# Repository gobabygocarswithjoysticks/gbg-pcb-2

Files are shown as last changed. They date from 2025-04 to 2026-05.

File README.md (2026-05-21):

# Moved to https://github.com/gobabygocarswithjoysticks/gbg-pcb

# GBG PCB

# A PCB for controlling the motors in a [go baby go car with joystick control](https://gobabygocarswithjoysticks.github.io/index/)

https://github.com/gobabygocarswithjoysticks/gbg-pcb



V2.1

This board replaces the control box of a car's original electronics or the separate ESCs and Arduino in the [usual joystick modification](https://gobabygocarswithjoysticks.github.io/index/). The board has screw terminals for connecting to the battery, motors, and the joystick. With this circuit board, a car can be converted to joystick control without any soldering.

Voltage input: 5 to 26 volts (6v, 12v, and 24v lead acid batteries, absolute maximum 4.6V-28V)

Controls two motors: one for each wheel so that the car can turn in place.

[New in version 2](https://gobabygocarswithjoysticks.github.io/gbg-pcb/instructions/instructions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): A V2 GBG-PCB can be configured with battery, motor, and signal plugs that match the plugs on the common weelye control boxes. This means some cars can be converted to joystick control without cutting any wires. V2 GBG-PCBs also run fron 6 to 24 volt batteries.

### For the previous versions of the GBG-PCB see https://github.com/gobabygocarswithjoysticks/gbg-pcb/tree/version_1 
Version 1 GBG-PCBs had a higher, 10 amp current capacity and a lower part count but requires 12 volts.

## Questions? Please email our support line at gbg-pcb@googlegroups.com

# Want one?
* Email pnwassistivetech@gmail.com or visit the [PNW Assistive Technology website](TODO/gbg-pcb). Thank you to PNWAT for supporting this project and being a supplier of these boards.
* Use this PCBWay link to order fully assembled boards: [PCBWay](https://www.pcbway.com/project/shareproject/GBG_PCB_Go_Baby_Go_Printed_Circuit_Board_V2_0_a8fd7fa3.html)
* Email gobabygocarswithjoysticks@gmail.com. I may have a small number of assembled V1 and V2 boards to sell or donate to you.
* Or please feel free to use these [files](/PCB_production) and get boards yourself. Instructions [here](https://gobabygocarswithjoysticks.github.io/gbg-pcb/instructions/how-to-make-boards)

# Software
## The website for uploading software to a GBG-PCB and adjusting settings is here: https://gobabygocarswithjoysticks.github.io/programmer/

# Instructions
## [general instructions for using this PCB](https://gobabygocarswithjoysticks.github.io/gbg-pcb/instructions/instructions)
### [instructions for assembling your own GBG-PCBs](https://gobabygocarswithjoysticks.github.io/gbg-pcb/instructions/how-to-make-boards)
## Index of Instructions for modifying specific models of cars using GBG-PCBs
* [Aosom Jeep - old model](https://gobabygocarswithjoysticks.github.io/gbg-pcb/instructions/car-specific/aosom-038-jeep/instructions) (car is out of production)
* [Zupapa Bumper Car](https://gobabygocarswithjoysticks.github.io/gbg-pcb/instructions/car-specific/zupapa-bumper-car/instructions) (instructions are complete through electronics but don't include a backrest or joystick holder)

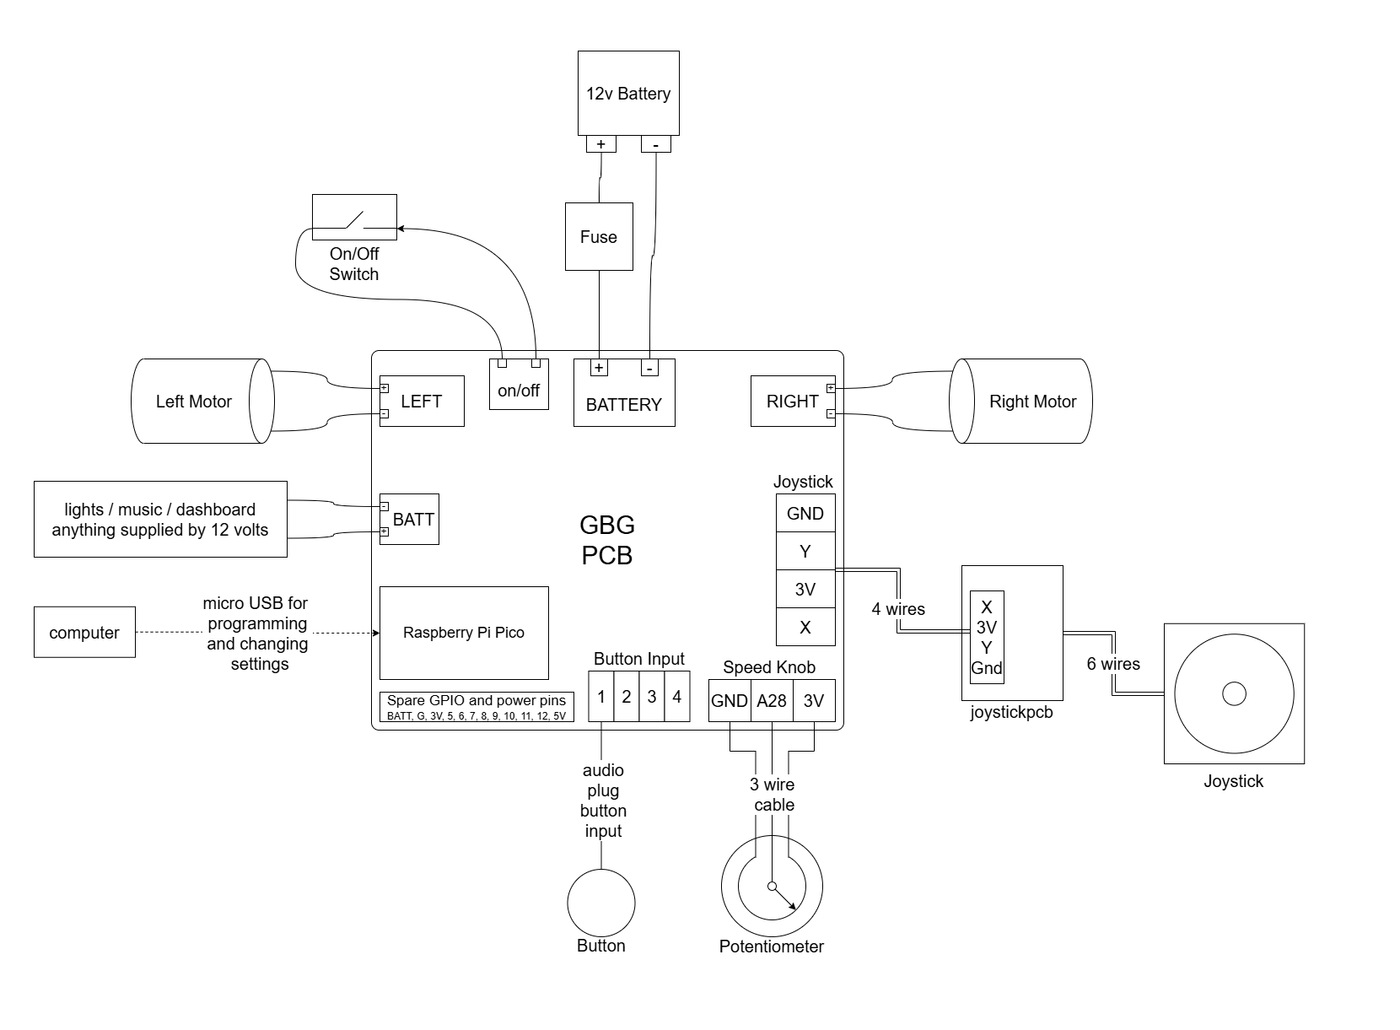
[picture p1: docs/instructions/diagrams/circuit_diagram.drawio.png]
schematic


# [schematic of PCB](/schematic.pdf)

# [PCB Production files](/PCB_production)

# [joystick to 4 wire cable connector PCB](https://github.com/gobabygocarswithjoysticks/gbg-pcb/tree/main/joystickpcb)
### This keeps you from needing to solder the joystick wires to a 4 wire cable.

# notes for people working on the KiCAD for this project
Use KiCAD 10.0

Run [this github action](https://github.com/gobabygocarswithjoysticks/gbg-pcb/actions/workflows/process-kicad.yml) when you push changes to any of the KiCAD files. The action updates the images of the CAD, the gerber files, the schematic, and other PCB production files. 

# photos
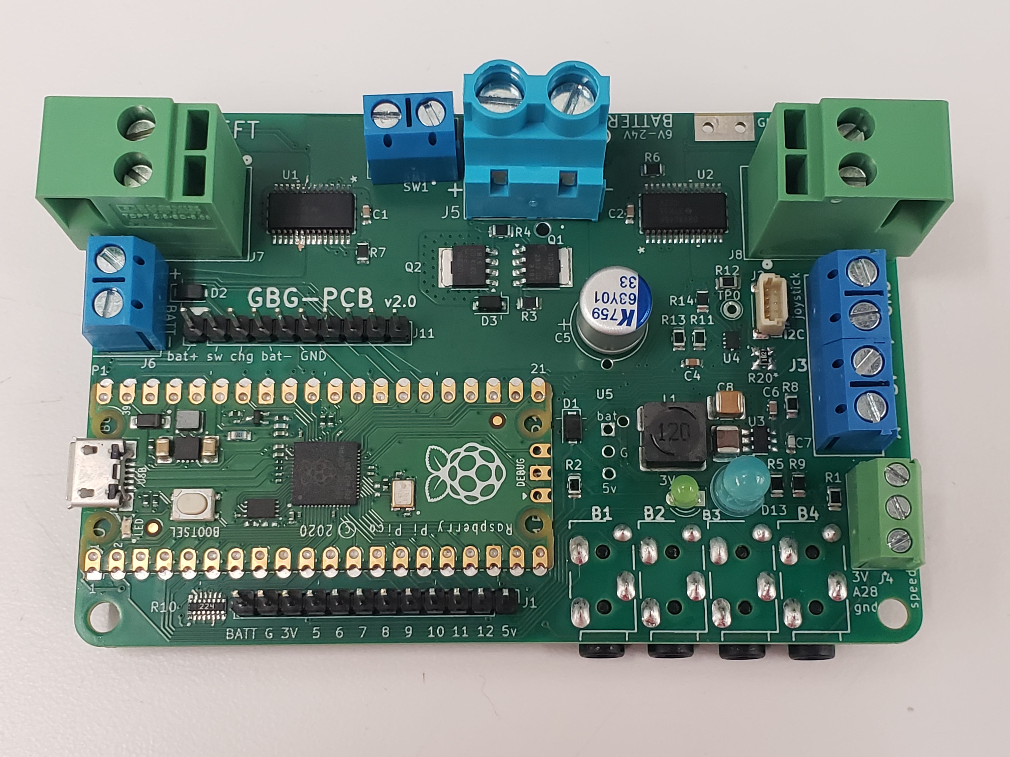
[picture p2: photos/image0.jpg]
view of assembled PCB from the top

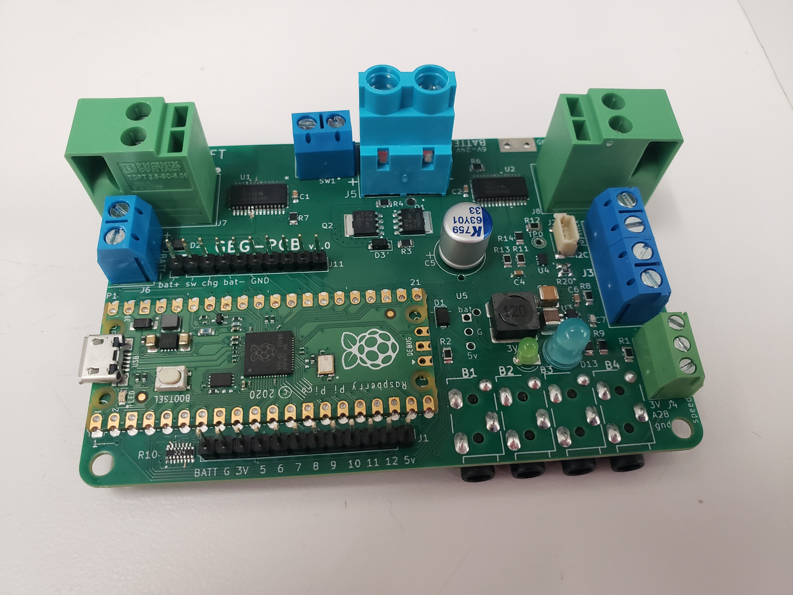
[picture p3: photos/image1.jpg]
view of assembled PCB


# images of CAD

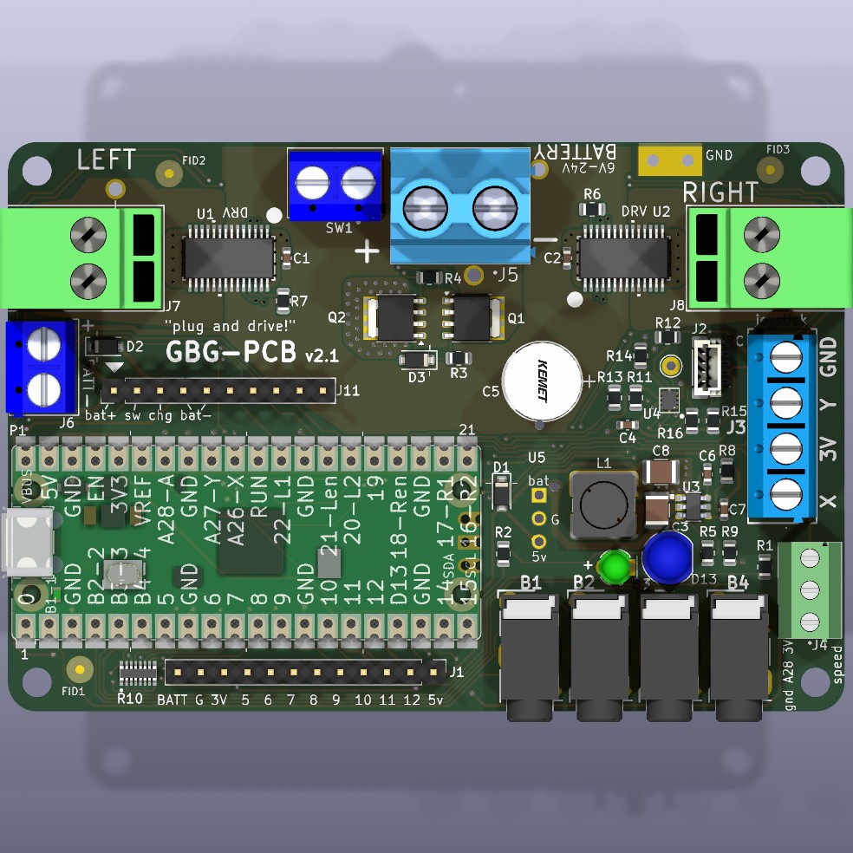
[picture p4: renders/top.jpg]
auto generated image, top view

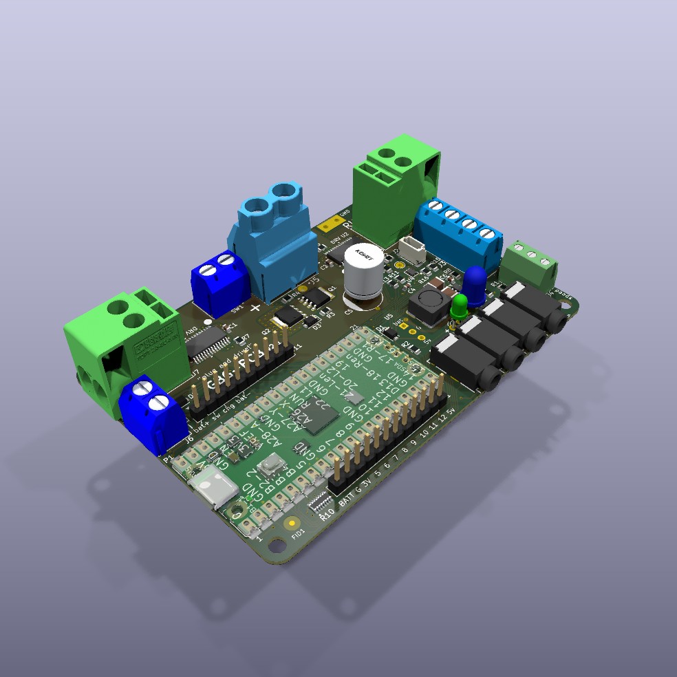
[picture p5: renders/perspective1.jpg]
auto generated image, p1

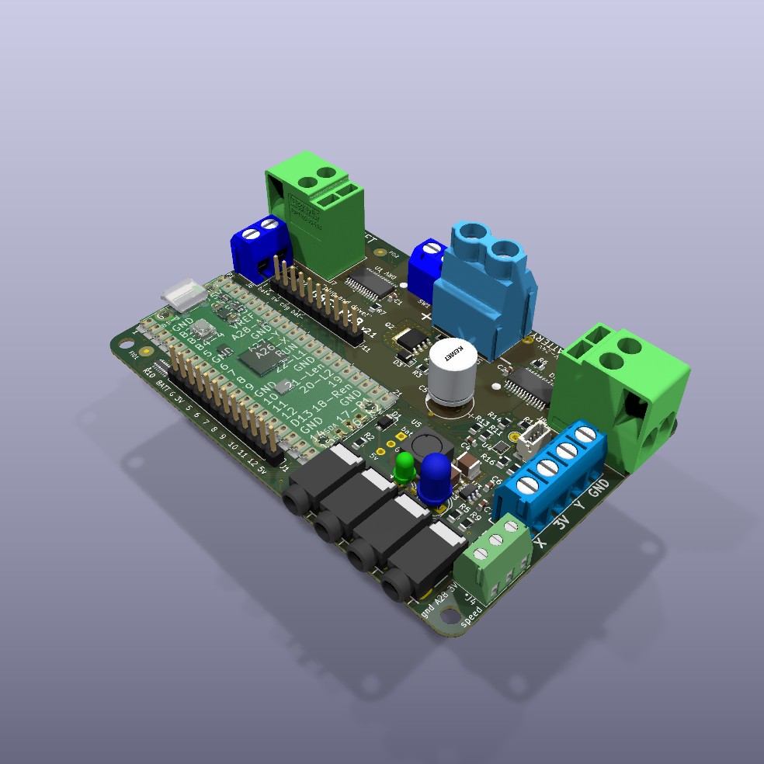
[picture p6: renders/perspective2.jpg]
auto generated image, p2

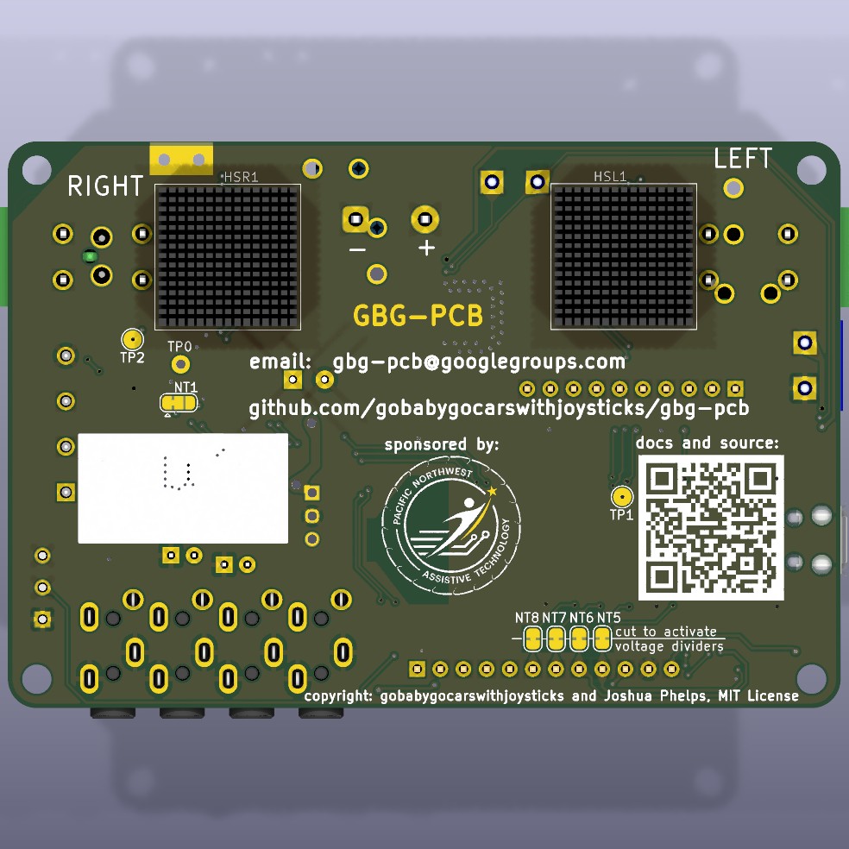
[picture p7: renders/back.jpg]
auto_generated_image, back


# credits

## Prototype boards sponsored by PNW Assistive Technology

## This project was inspired by the [Go Baby Go project](https://health.oregonstate.edu/gobabygo) that modifies powerwheels cars for kids with disabilities

## Copyright: gobabygocarswithjoysticks and Joshua Phelps, MIT License

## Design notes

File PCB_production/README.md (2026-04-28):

## instructions for how to make GBG-PCBs by hand are [here](https://gobabygocarswithjoysticks.github.io/gbg-pcb/instructions/how-to-make-boards)

## send [gerbers.zip](/PCB_production/gerbers.zip) to a PCB fabrication company

## [F_SolderPasteMask.dxf](/PCB_production/F_SolderPasteMask.dxf) can be used to get a solder stencil

## The [position.csv](/PCB_production/position.csv) file has the locations for the surface mount components

## Bill Of Materials (BOM)
please email gobabygocarswithjoysticks@gmail.com if components are out of stock and you need recommendations for alternatives

[BOM.csv](/PCB_production/BOM.csv) is the normal list of parts (using screw terminals for connections).

[BOM-with-DNP.csv](/PCB_production/BOM-with-DNP.csv) includes alternative parts that you could choose some of, for other configurations of the board.

Here is BOM.csv uploaded to a [Digikey list](https://www.digikey.com/en/mylists/list/1ZSY7GGAFQ)

## [joystick to 4 wire cable connector PCB](https://github.com/gobabygocarswithjoysticks/gbg-pcb/tree/main/joystickpcb)
This keeps you from needing to solder the joystick wires to a 4 wire cable.

## [interactive BOM to help with assembly](https://gobabygocarswithjoysticks.github.io/gbg-pcb-2/ibom/ibom.html)

## parameters for PCBs:
* 1oz copper
* 1.0mm board thickness
* 5mil/5mil
* 0.25mm holes
* solder stencils should be 0.12mm
* solder stencils should be "non-framework"
* I suggest lead-free HASL, but match your solder type

## other configurations

### alternate voltage regulator (U5)
Replace U3, C3, R5, C6, L1, C7, R8, R9, C8

Choose a single THT module that outputs 5V. Make sure the pinout matches. Make sure hte min and max input voltage are compatible with your battery. It's ok if the output voltage sags below 5 volts as the input approaches 5 volts but make sure the regulator you choose doesn't start blinking on and off as the input approaches 5 volts, if you plan to use cars with 6 volt batteries.

Consider pololu5593, D78B05T, RBT05W24S05

### alternate battery and motor connectors (Weelye mode)
The GBG-PCB includes pads for adding connectors that match the connectors on some common weelye control boxes like the RX22 and RX7.

* J102 and J103 replace J5
* J100 and J101 replace J7
* J104 replaces J8

### other models of Raspberry Pi Pico (P1)
If you want to be able to change settings and remote override the car over a wifi connection [(see information here)](https://github.com/gobabygocarswithjoysticks/car-code/blob/main/rcdocs/remote_control.md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) then you can substitute a Pico 1W or Pico 2W for the standard Pico 1.

### cost saving by removing optional features

#### button ports
If you know that you will only use joystick input and won't use button input you can omit 

B1, B2, B3, B4

#### i2c connector
If you don't plan to connect I2C devices (most likely you don't need this) you can omit

J2

#### battery and current monitor
If you don't need the PCB to be able to detect low battery voltage or how much current the motors are drawing you can omit the following parts:

U4, R11, R12, R13, R14, R20, C4

#### speed knob
If you know that you will not install a speed adjustment knob you can omit 

J4

#### [consider an alternate voltage regulator](https://github.com/gobabygocarswithjoysticks/gbg-pcb-2/blob/main/PCB_production/README.md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)

Using a THT module might not be significantly cheaper but it could save you time during assembly.

## questions for suppliers to ask
* pico1 or pico1W?
* include button jacks?
* include chip that monitors voltage and current?
* screw terminals or "weelye mode"?
    * if weelye mode, the standard headers for J11 could be changed to match the specific boards you're using

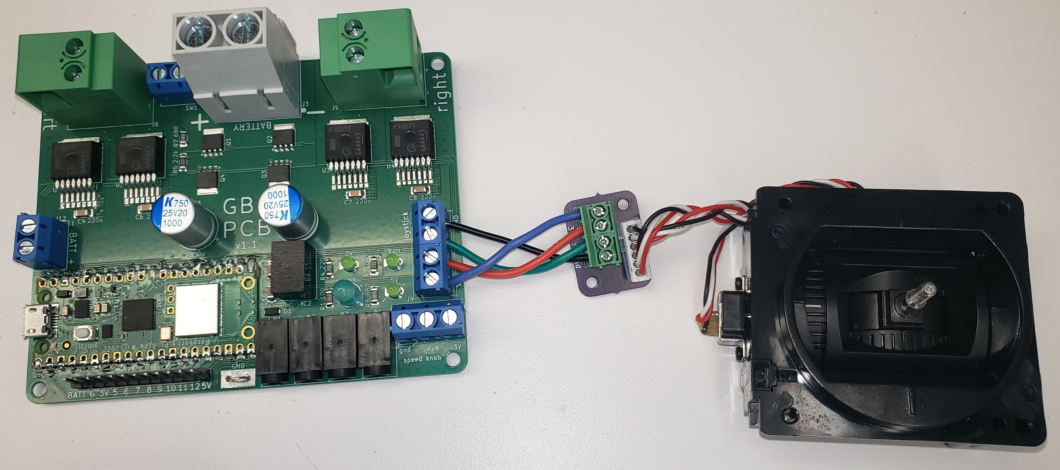
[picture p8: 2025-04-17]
photos/joystick.jpg

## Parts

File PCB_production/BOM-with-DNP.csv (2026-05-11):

Reference | Value | Footprint | Manufacturer_Name | Manufacturer_Part_Number | digikey_part_number | mount_type | QUANTITY
3V1 | green | LED_THT:LED_D3.0mm | American Bright Optoelectronics Corporation | BL-B2141K | 2007-BL-B2141K-ND | tht | 1
B1-B4 | ASJ-200-B-HT | kicad libraries:ASJ200BHT | Adam Tech | ASJ-200-B-HT | 2057-ASJ-200-B-HT-ND | tht | 4
C1,C2,C4,C6 | 0.1uF | Capacitor_SMD:C_0603_1608Metric | TDK Corporation | CGA3E2X7R1H104K080AA | 445-5666-1-ND | smd | 4
C3 | 10uF | Capacitor_SMD:C_1210_3225Metric | Taiyo Yuden | MSASU32MSB5106KPNA01 | 587-MSASU32MSB5106KPNA01CT-ND | smd | 1
C5 | 33uf | kicad libraries:CAP_KK-8x8_KEM | KEMET | A759KK336M1JAAE036 | 399-A759KK336M1JAAE036-ND | tht | 1
C7 | 56pF | Capacitor_SMD:C_0603_1608Metric | Yageo | CC0603JRNPO9BN560 | 311-1066-1-ND | smd | 1
C8 | 47uF | Capacitor_SMD:C_1210_3225Metric | MuRata | GRM32ER71A476KE15L | 490-5312-1-ND | smd | 1
D1,D2 | D_Schottky | Diode_SMD:D_SOD-123F | Good-Ark Semiconductor | FS26 | 4786-FS26CT-ND | smd | 2
D3 | 18V zener | Diode_SMD:D_SOD-123F | Vishay General Semiconductor - Diodes Division | MMSZ5248B-E3-18 | MMSZ5248B-E3-18GICT-ND | smd | 1
D13 | blue | LED_THT:LED_D5.0mm | American Bright Optoelectronics Corporation | BL-BBX1V4V-2-B02 | 2007-BL-BBX1V4V-2-B02-ND | tht | 1
HSL1,HSR1 | Heatsink | kicad libraries:heatsink 375424B00034G | Boyd Laconia, LLC | 375424B00034G | 375424B00034G-ND | tht | 2
J1 | 12 2.54mm pitch header pins | Connector_PinHeader_2.54mm:PinHeader_1x12_P2.54mm_Vertical | Any Manufacturer | PH1-12-UA | 2057-PH1-12-UA-ND | tht | 1
J2 | Conn_01x04 | Connector_JST:JST_SH_BM04B-SRSS-TB_1x04-1MP_P1.00mm_Vertical | JST Sales America Inc. | BM04B-SRSS-TB | 455-BM04B-SRSS-TBCT-ND | smd | 1
J3 | joystick | kicad libraries:TC0403620000G | Amphenol Anytek | TC0403620000G | TC0403620000G-ND | tht | 1
J4 | speed knob | kicad libraries:SAMESKY_TB0011-350-03GR | Same Sky (Formerly CUI Devices) | TB0011-350-03GR | 2223-TB0011-350-03GR-ND | tht | 1
J5 | TB005-762-02BE | kicad libraries:CUI_TB005-762-02BE | Same Sky (Formerly CUI Devices) | TB005-762-02BE | 102-6189-ND | tht | 1
J6,SW1 | screw terminal | kicad libraries:EBBA-02-C-SS-BU | Adam Tech | EBBA-02-C-SS-BU | 2057-EBBA-02-C-SS-BU-ND | tht | 2
J7,J8 | 1017491 | kicad libraries:CONN_1017491 | Phoenix Contact | 1017491 | 277-17493-ND | tht | 2
J11 | Conn_01x10_Pin | Connector_PinHeader_2.54mm:PinHeader_1x10_P2.54mm_Vertical | Any Manufacturer | PH1-10-UA | 2057-PH1-10-UA-ND | tht | 1
J100-J103 | 0197054001 | kicad libraries:0197054001 | Molex | 0197054001 | WM2982-ND | tht | 4
J104 | wellye style | kicad libraries:CONN02_2159151002_MOL | Molex | 2159151002 | 23-2159151002-ND | tht | 1
J105 | wellye RX25 style | kicad libraries:TE_1-1123723-2 | TE Connectivity AMP Connectors | 1-1123723-2 | A111830-ND | tht | 1
L1 | 12uH | kicad libraries:IND_SRR6038-120Y | Bourns | SRR6038-120Y | SRR6038-120YCT-ND | smd | 1
P1 | rpi pico 1 | Module:RaspberryPi_Pico_Common_SMD | Raspberry Pi | SC0915 | 2648-SC0915CT-ND | tht | 1
Q1,Q2 | PSMN1R2-25YLDX | Package_TO_SOT_SMD:LFPAK56 | Nexperia USA Inc. | PSMN1R2-25YLDX | 1727-2496-1-ND | smd | 2
R1,R2 | 220 | Resistor_SMD:R_0805_2012Metric | Vishay Dale | CRCW0805220RJNEA | 541-220ACT-ND | smd | 2
R3,R15,R16 | 3.3k | Resistor_SMD:R_0805_2012Metric | Vishay Dale | CRCW08053K30FKEA | 541-3.30KCCT-ND | smd | 3
R4,R9 | 13.7k | Resistor_SMD:R_0805_2012Metric | Vishay Dale | CRCW080513K7FKEA | 541-13.7KCCT-ND | smd | 2
R5,R8,R13 | 100k | Resistor_SMD:R_0805_2012Metric | Vishay Dale | CRCW0805100KFKEA | 541-100KCCT-ND | smd | 3
R6,R7,R14 | 8.2k | Resistor_SMD:R_0805_2012Metric | Vishay Dale | CRCW08058K20JNEA | 541-8.2KACT-ND | smd | 3
R10 | 220k | kicad libraries:YC248-JR | YAGEO | YC248-JR-07220KL | 13-YC248-JR-07220KLCT-ND | smd | 1
R11,R12 | 604 | Resistor_SMD:R_0805_2012Metric | Vishay Dale | CRCW0805604RFKEA | 541-604CCT-ND | smd | 2
U1,U2 | DRV8245HQPWPRQ1 | kicad libraries:HTSSOP28_PWP_TEX | Texas Instruments | DRV8245HQPWPRQ1 | 296-DRV8245HQPWPRQ1CT-ND | smd | 2
U3 | TPS54202HDDCR | kicad libraries:SOT95P280X110-6N tps54202HDDCR | Texas Instruments | TPS54202HDDCR | 296-44396-1-ND | smd | 1
U4 | TLA2024IRUGR | kicad libraries:IC_TLA2024IRUGR | Texas Instruments | TLA2024IRUGR | 296-51661-1-ND | smd | 1

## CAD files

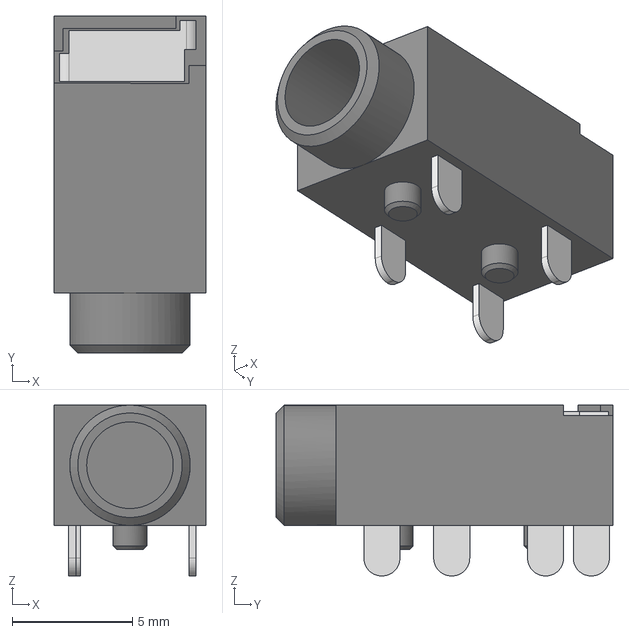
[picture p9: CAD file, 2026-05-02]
kicad/kicad libraries/ASJ-200-B-HT.stp
6.30 x 14.0 x 7.10 mm

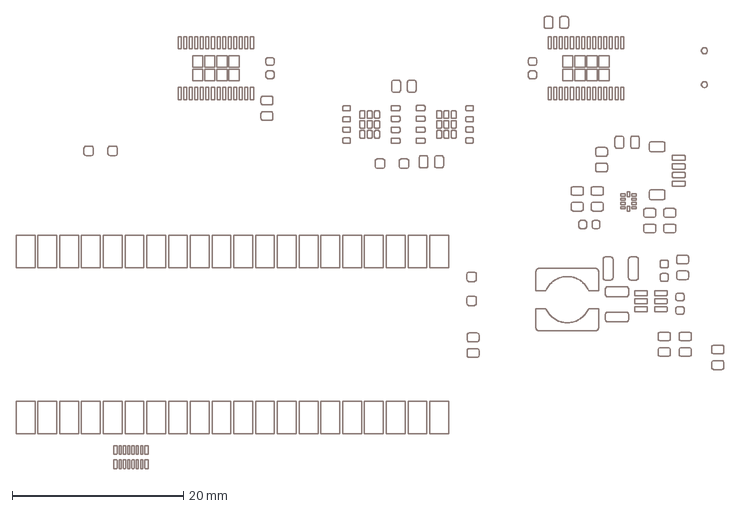
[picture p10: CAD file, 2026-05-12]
PCB_production/F_SolderPasteMask.dxf
82.6 x 52.7 mm

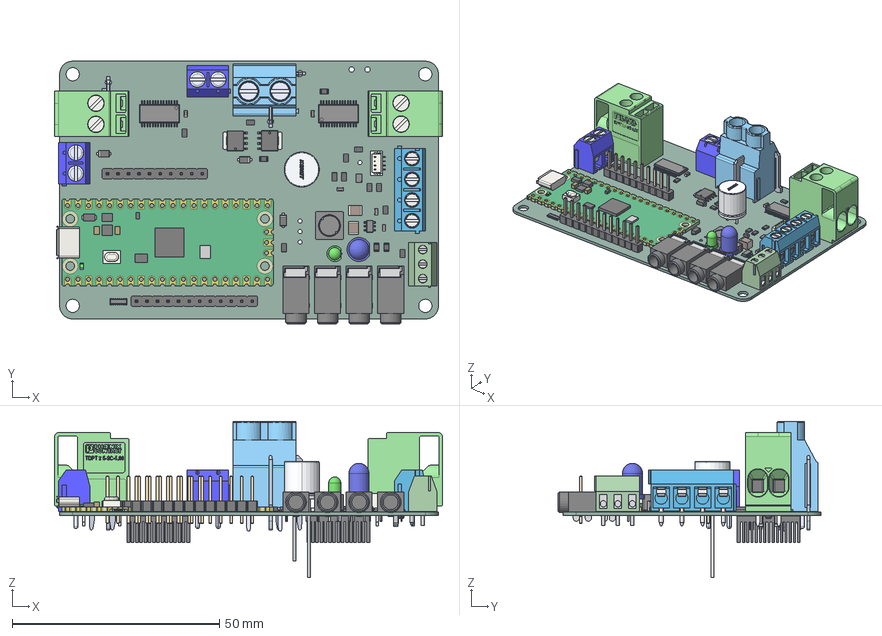
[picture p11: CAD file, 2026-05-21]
renders/gbg-pcb.step
93.6 x 63.4 x 37.7 mm
Resistor_Array_YC_AF_xxx_YC248-FR-07100KL
ADS1115IRUGR
ASJ-200-B-HT x 4
EBBA-02-C-SS-BU x 2
SRR6038-6R2Y
C_0603_1608Metric x 5
R_0805_2012Metric x 15
TB005-762-02P_Blue - S
C-1-1123723-2
BODY-TSSOP x 2
LEAD-TSSOP x 56
DAP x 2
JST_SH_BM04B-SRSS-TB_1x04-1MP_P1.00mm_Vertical
DDC6
PinHeader_1x12_P254mm_Vertical
CAR_KP_8X8_D8.5L9S3.5F0.65
adbeea53-9c39-11ed-93f0-dde97e994e83_part x 2
adbeea54-9c39-11ed-93f0-dde97e994e83_part x 2
adbeea55-9c39-11ed-93f0-dde97e994e83_part x 2
PinHeader_1x10_P254mm_Vertical
TB0011-350-03GR
C_1210_3225Metric x 2
D_SOD_123F x 3
LED_D5.0mm
TC0403620000G
LED_D3.0mm
RaspberryPi_Pico_Module_KiCad
375424B00034G x 2
gbg-pcb_PCB

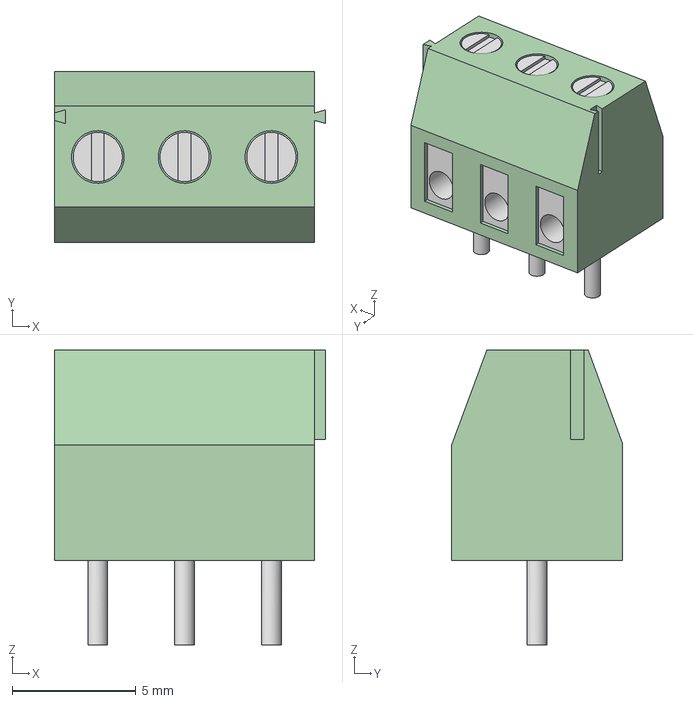
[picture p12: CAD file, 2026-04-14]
kicad/kicad libraries/TB0011-350-03GR.stp
10.9 x 6.90 x 11.9 mm

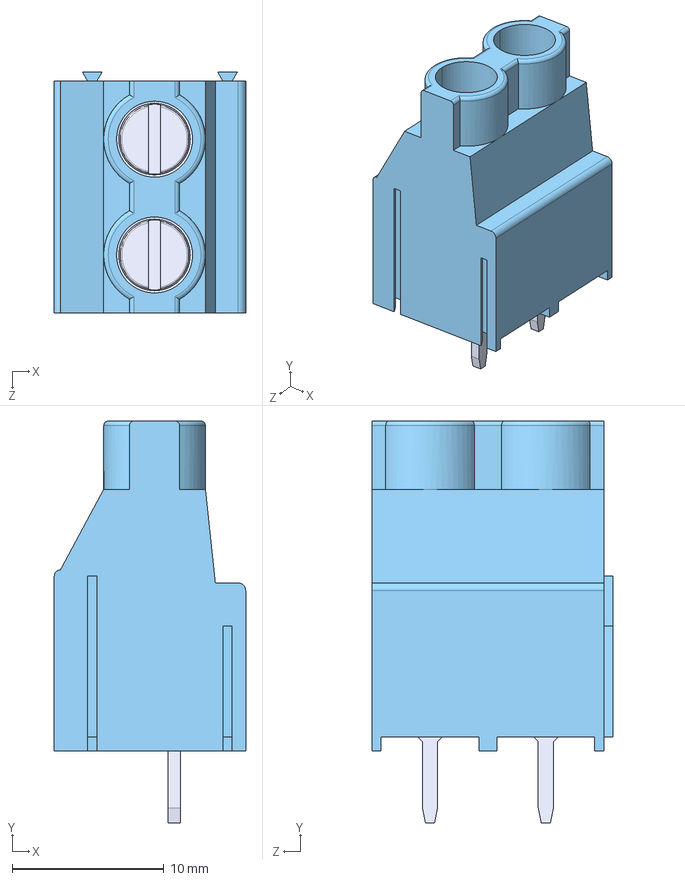
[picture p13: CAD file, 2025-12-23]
kicad/kicad libraries/TB005-762-02BE.step
12.6 x 26.5 x 15.8 mm

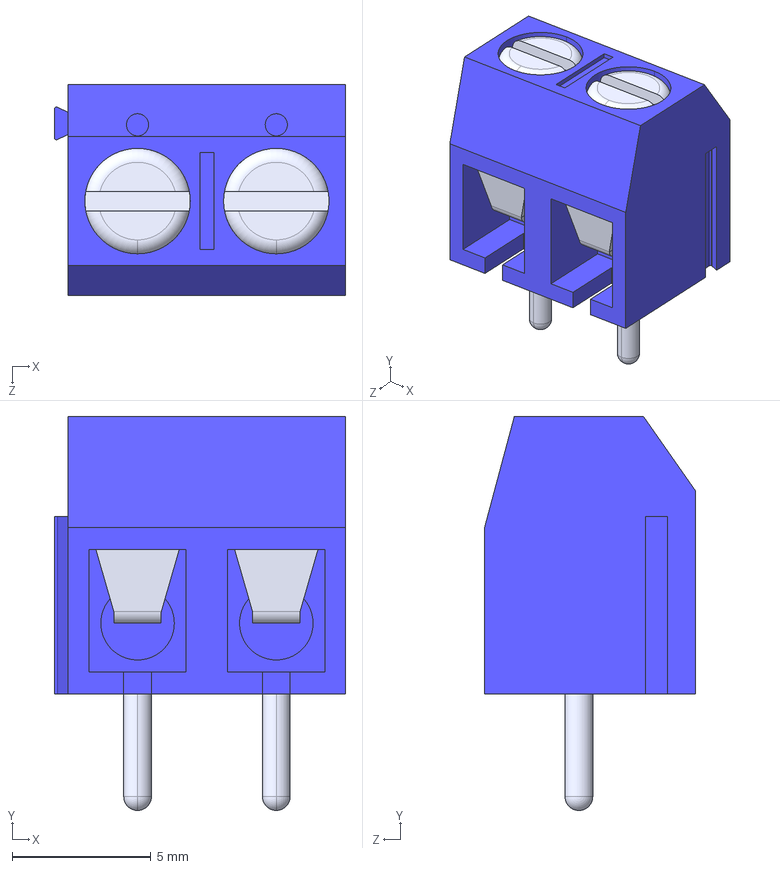
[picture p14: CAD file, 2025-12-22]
kicad/kicad libraries/EBBA-02-C-SS-BU--3DModel-STEP-510211.STEP
10.5 x 14.2 x 7.60 mm

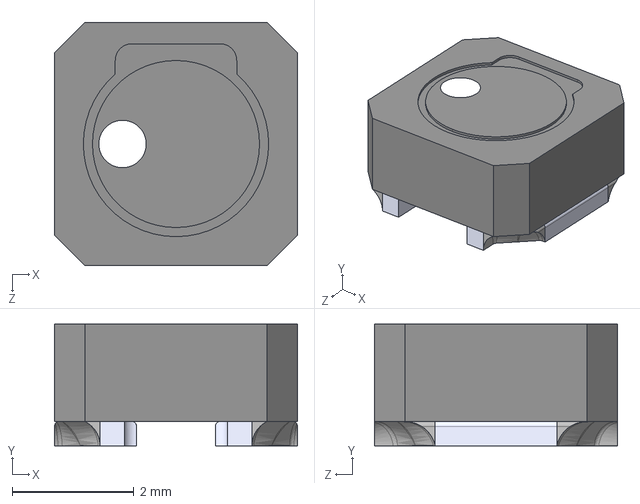
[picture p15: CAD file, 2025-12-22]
kicad/kicad libraries/VLCF4020T-270MR48--3DModel-STEP-56544.STEP
4.00 x 2.00 x 4.00 mm

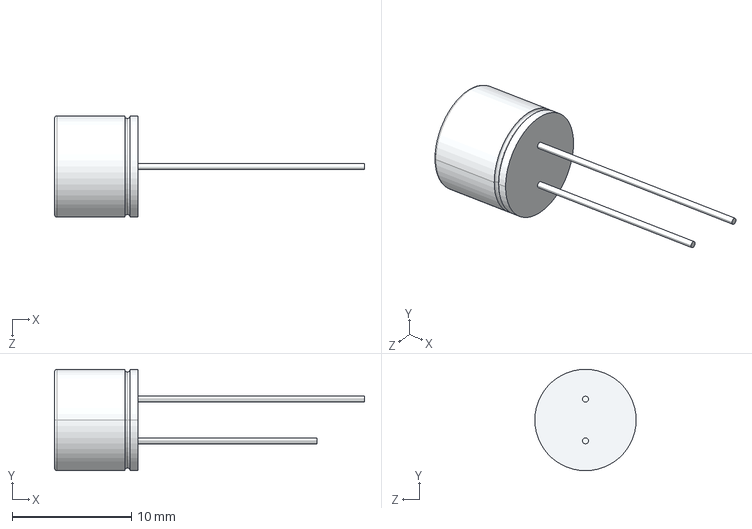
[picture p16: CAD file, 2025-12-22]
kicad/kicad libraries/A759KC276M1JAAE054.step
26.0 x 8.50 x 8.50 mm

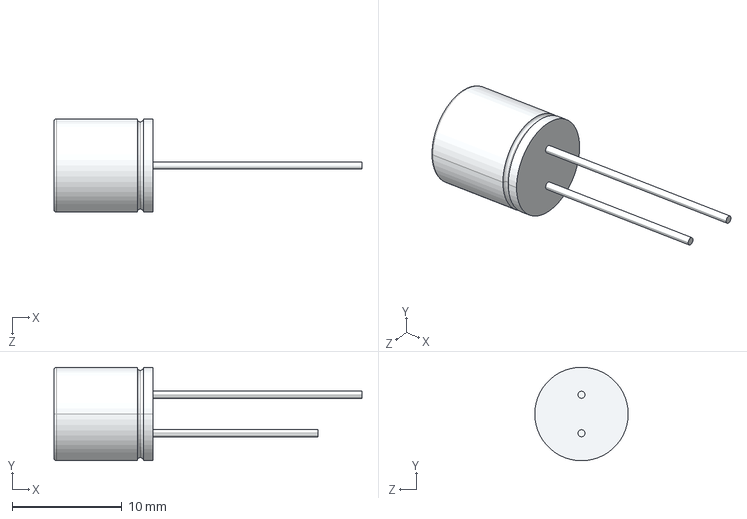
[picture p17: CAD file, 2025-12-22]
kicad/kicad libraries/A759KK336M1JAAE036.step
28.0 x 8.50 x 8.50 mm

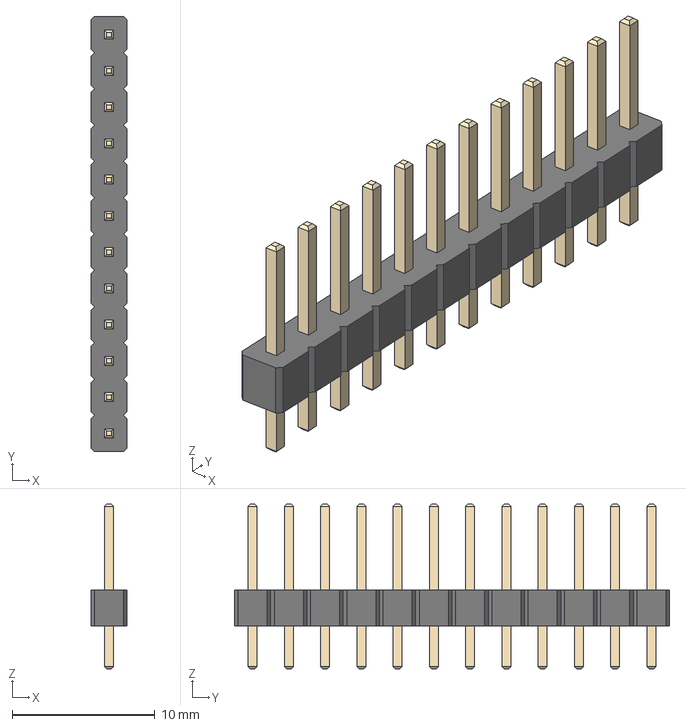
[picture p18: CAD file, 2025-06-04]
kicad/kicad libraries/PinHeader_1x12_P2.54mm_Vertical.step
2.54 x 30.5 x 11.5 mm

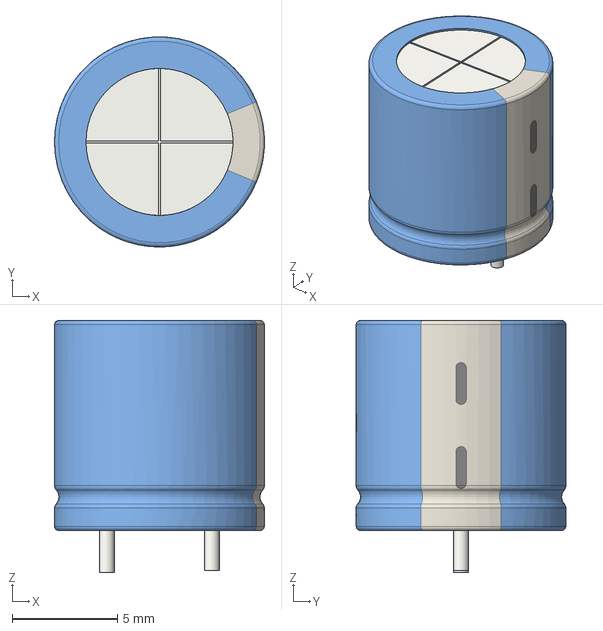
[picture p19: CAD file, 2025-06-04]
kicad/kicad libraries/CP_Radial_D10.0mm_P5.00mm.step
10.00 x 9.99 x 12.0 mm

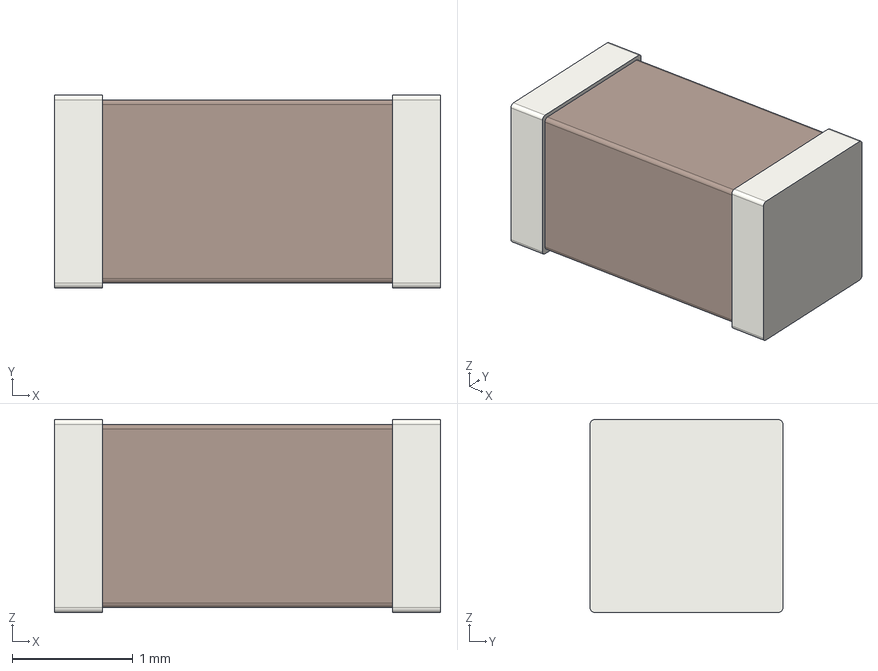
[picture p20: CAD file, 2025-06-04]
kicad/kicad libraries/C_1206_3216Metric.step
3.20 x 1.60 x 1.60 mm

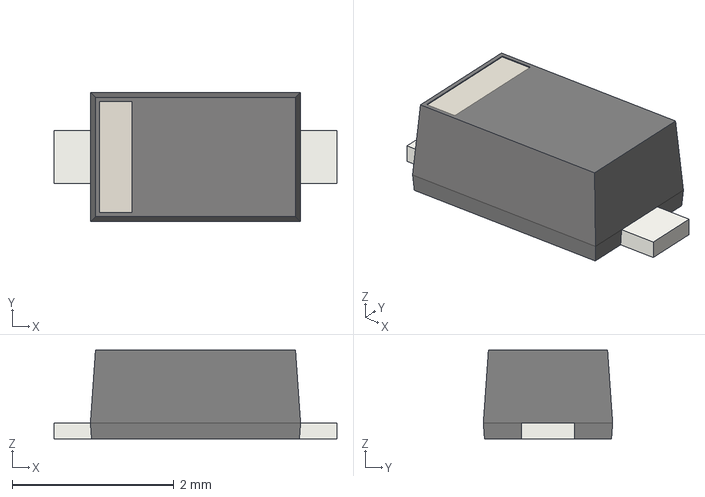
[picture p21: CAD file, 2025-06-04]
kicad/kicad libraries/D_SOD-123F.step
3.50 x 1.60 x 1.10 mm

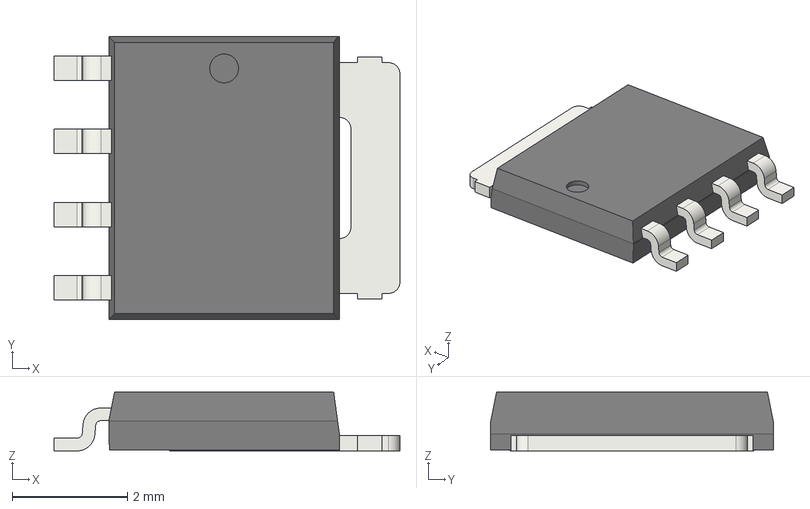
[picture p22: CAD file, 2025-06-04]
kicad/kicad libraries/LFPAK56.step
6.00 x 4.90 x 1.02 mm
adbeea53-9c39-11ed-93f0-dde97e994e83_part
adbeea54-9c39-11ed-93f0-dde97e994e83_part
adbeea55-9c39-11ed-93f0-dde97e994e83_part

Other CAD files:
kicad/kicad libraries/R_1206_3216Metric.step
kicad/kicad libraries/v2027b.stp
kicad/kicad libraries/sk582.stp
kicad/kicad libraries/0398800304.stp
kicad/kicad libraries/1017491.stp
kicad/kicad libraries/1017503.stp
kicad/kicad libraries/1017514.stp
kicad/kicad libraries/1017526.stp
kicad/kicad libraries/1715721.stp
kicad/kicad libraries/1mmcube.step
kicad/kicad libraries/2376591-2.stp
kicad/kicad libraries/375424B00034G.stp
kicad/kicad libraries/63900-1--3DModel-STEP-1(1).STEP
kicad/kicad libraries/A750MV108M1EAAE014.step
kicad/kicad libraries/D78B05T-1.0.step
kicad/kicad libraries/DPAK_0031EL_GE3_VIS.step
kicad/kicad libraries/DRV8245HQPWPRQ1.stp
kicad/kicad libraries/IFX007TAUMA1.step
kicad/kicad libraries/OSTTC0201X2.stp
kicad/kicad libraries/OSTTC0321X2.stp
kicad/kicad libraries/OSTTC042162.STP
kicad/kicad libraries/POWERDI5_DIO.step
kicad/kicad libraries/SJ1-3523N.step
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

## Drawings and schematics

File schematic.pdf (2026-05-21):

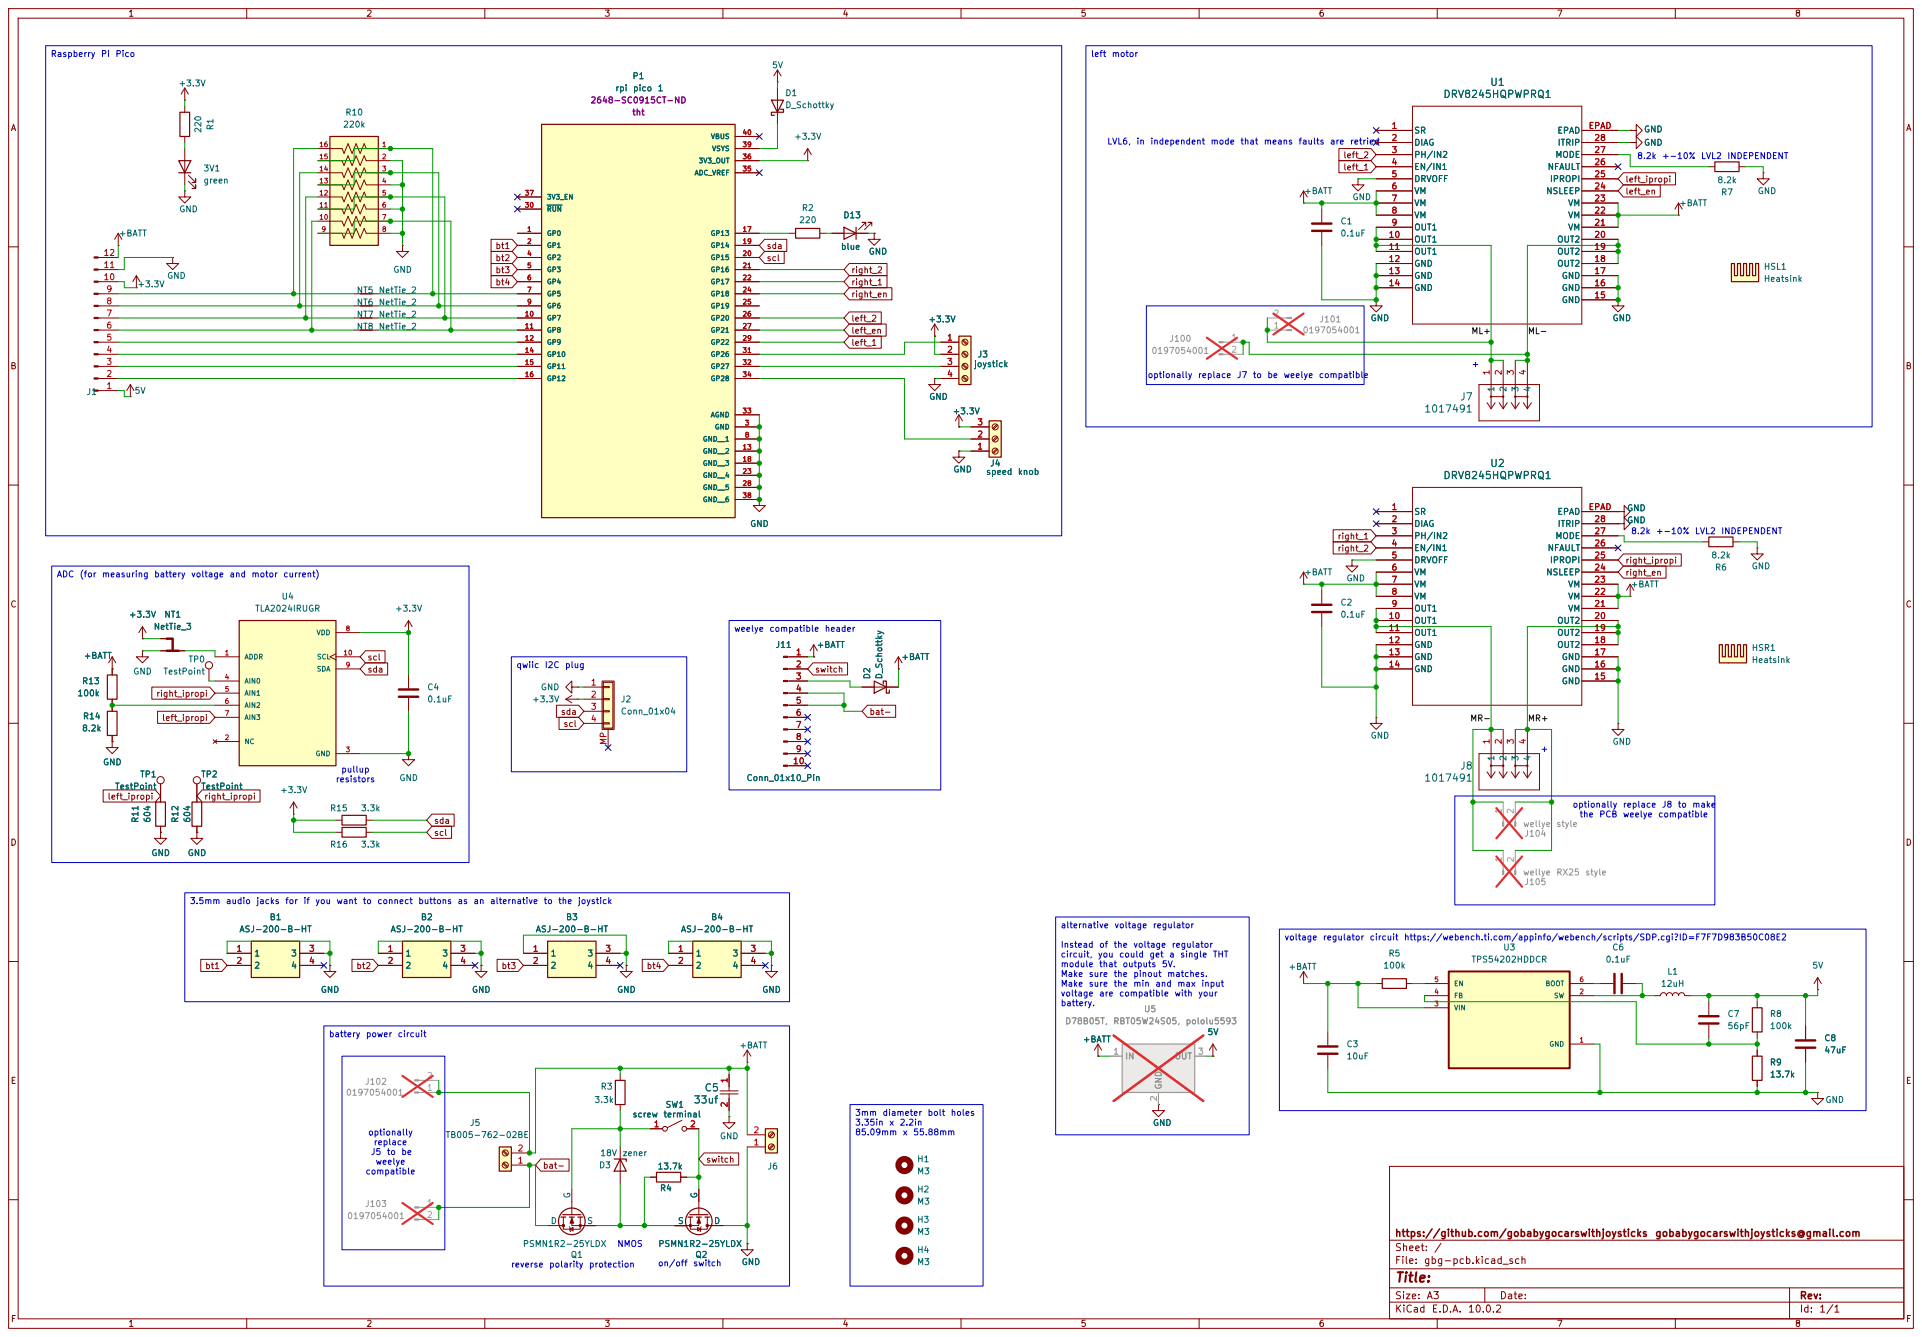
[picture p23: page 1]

green 220 R1 GND +BATT GND

LVL6, in independent mode that means faults are retried

8.2k +-10% LVL2 INDEPENDENT optionally replace J7 to be weelye compatible

the PCB weelye compatible 8.2k +-10% LVL2 INDEPENDENT

ADC (for measuring battery voltage and motor current)

optionally replace J8 to make

3.5mm audio jacks for if you want to connect buttons as an alternative to the joystick

voltage regulator circuit https://webench.ti.com/appinfo/webench/scripts/SDP.cgi?ID=F7F7D983B50C08E2

Instead of the voltage regulator
circuit, you could get a single THT module that outputs 5V. Make sure the pinout matches. Make sure the min and max input

voltage are compatible with your battery.

https://github.com/gobabygocarswithjoysticks gobabygocarswithjoysticks@gmail.com
Sheet: /
File: gbg-pcb.kicad_sch
Title:

Size: A3 | Rev:
KiCad E.D.A. 10.0.2 | Id: 1/1 | F Date:

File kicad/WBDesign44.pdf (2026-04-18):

## WEBENCH ® Design Report

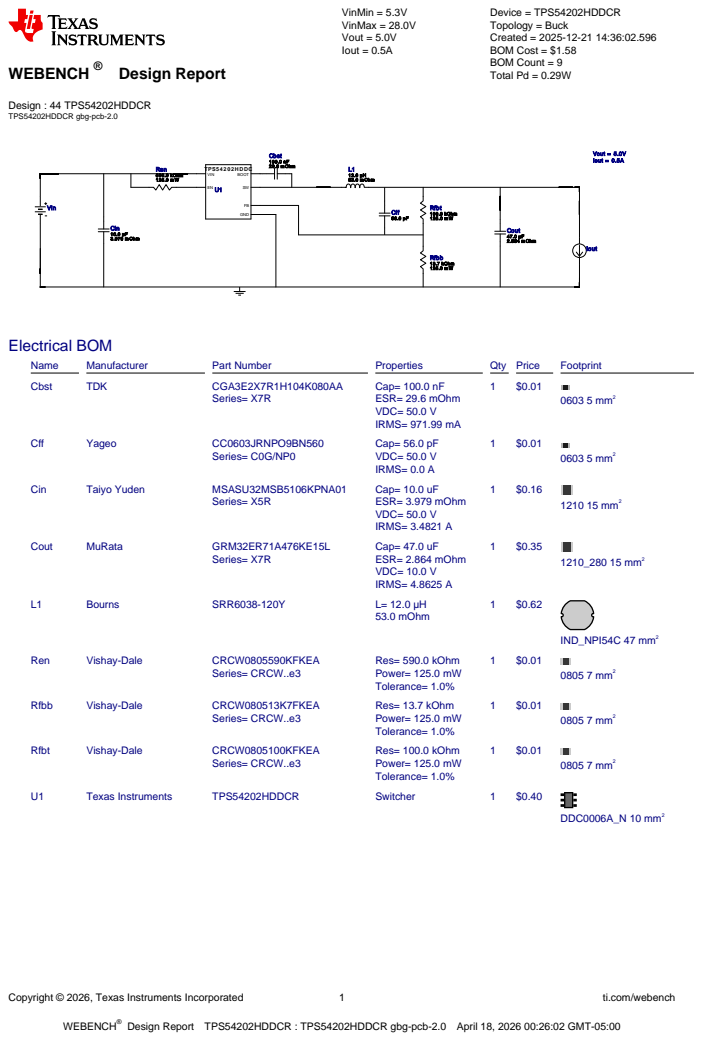
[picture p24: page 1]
Copyright © 2026, Texas Instruments Incorporated; ti.com/webench; WEBENCH®; Design : 44 TPS54202HDDCR TPS54202HDDCR gbg-pcb-2.0; VinMin = 5.3V VinMax = 28.0V Vout = 5.0V Iout = 0.5A; Device = TPS54202HDDCR Topology = Buck Created = 2025-12-21 14:36:02.596 BOM Cost = $1.58 BOM Count = 9 Total Pd = 0.29W; Cbst 100.0 nF; 29.6 m Ohm; Cin 10.0 µF 3.979 m Ohm; Cout 47.0 µF; 2.864 m Ohm; L1 12.0 µH 53.0 m Ohm; Ren 590.0 kOhm 125.0 m W; Rfbb 13.7 kOhm 125.0 m W; Rfbt 100.0 kOhm; TPS5 4 2 0 2 HDDC; GND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

Design Report TPS54202HDDCR : TPS54202HDDCR gbg-pcb-2.0 April 18, 2026 00:26:02 GMT-05:00

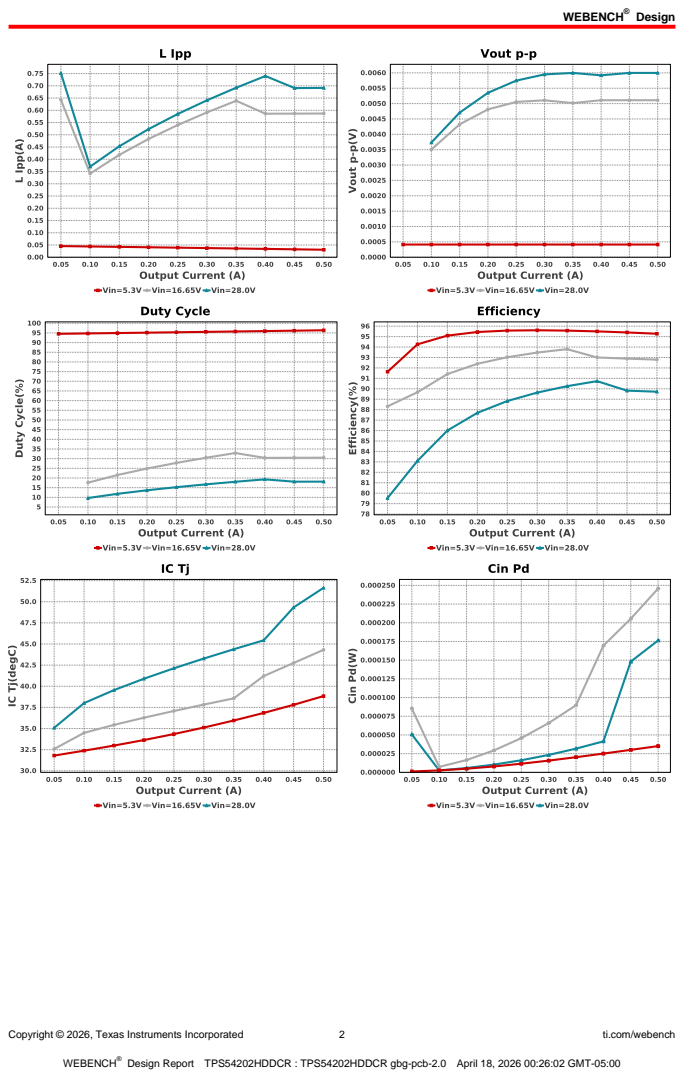
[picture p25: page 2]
Design; Copyright © 2026, Texas Instruments Incorporated; ti.com/webench

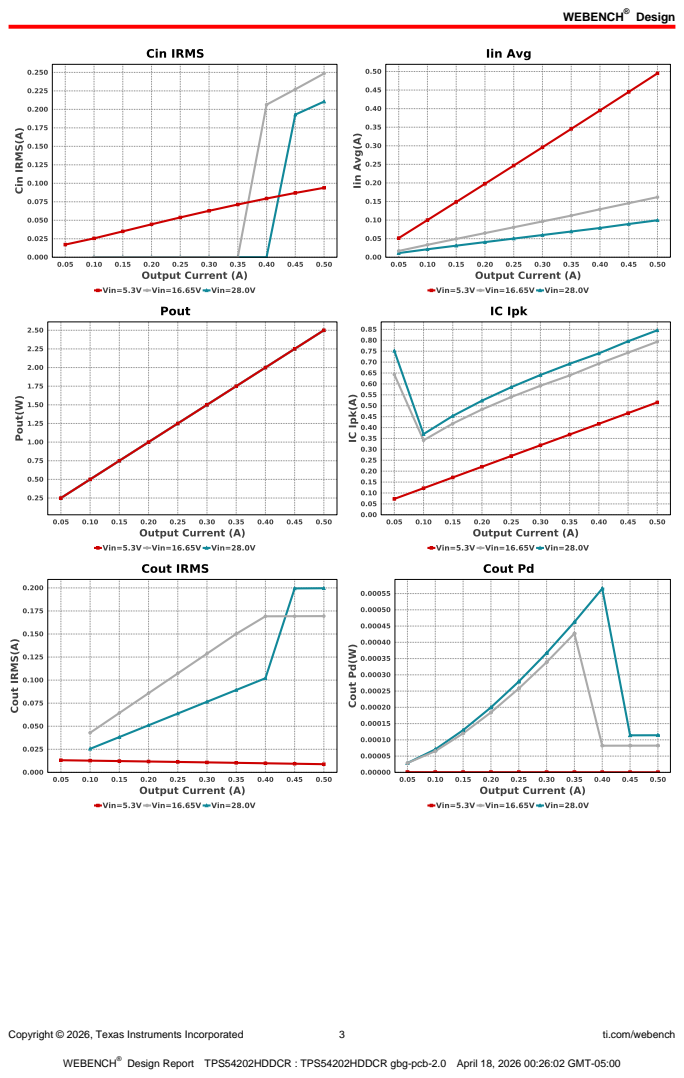
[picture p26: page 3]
Copyright © 2026, Texas Instruments Incorporated; ti.com/webench

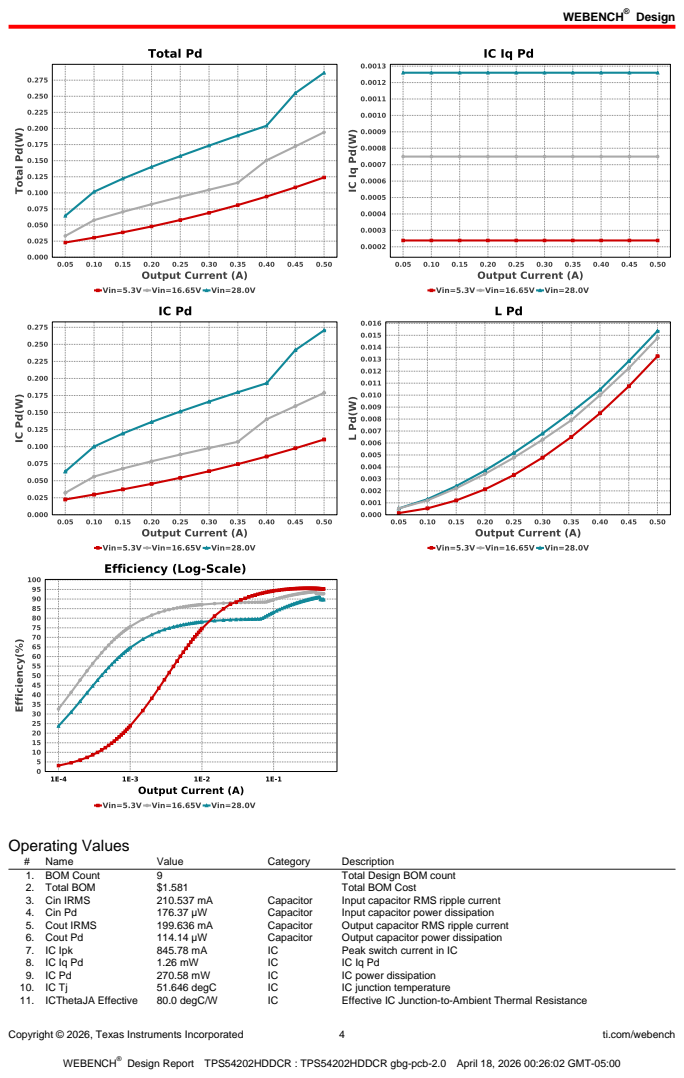
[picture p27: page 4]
Copyright © 2026, Texas Instruments Incorporated; ti.com/webench; Operating Values; Name; Value; Category; Description; 1. BOM Count; Total Design BOM count; 2. Total BOM; Total BOM Cost; 3. Cin IRMS; Capacitor; Input capacitor RMS ripple current; 4. Cin Pd; Input capacitor power dissipation; 5. Cout IRMS; Output capacitor RMS ripple current; 6. Cout Pd; Output capacitor power dissipation; 7. IC Ipk; Peak switch current in IC; IC power dissipation; 51.646 degC; IC junction temperature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

Copyright © 2026, Texas Instruments Incorporated | 5 | ti.com/webench
# | Name | Value | Category | Description

12. Iin Avg | 99.516 mA | IC | Average input current
13. L Ipp | 691.559 mA | Inductor | Peak-to-peak inductor ripple current
14. L Pd | 15.362 mW | Inductor | Inductor power dissipation
15. Cin Pd | 176.37 µW | Power | Input capacitor power dissipation
16. Cout Pd | 114.14 µW | Power | Output capacitor power dissipation
17. IC Pd | 270.58 mW | Power | IC power dissipation
18. L Pd | 15.362 mW | Power | Inductor power dissipation
19. Total Pd | 286.447 mW | Power | Total Power Dissipation
20. Duty Cycle | 18.126 % | System
| | | Information | Duty cycle
21. Efficiency | 89.72 % | System
| | | Information | Steady state efficiency
22. FootPrint | 147.0 mm² | System
| | | Information | Total Foot Print Area of BOM components
23. Frequency | 500.0 kHz | System
| | | Information | Switching frequency
24. Iout | 500.0 mA | System
| | | Information | Iout operating point
25. Mode | CCM | System
| | | Information | PWM/PFM Mode
26. Pout | 2.5 W | System
| | | Information | Total output power
27. Vin | 28.0 V | System
| | | Information | Vin operating point
28. Vout Actual | 4.98 V | System
| | | Information | Vout Actual calculated based on selected voltage divider resistors
29. Vout Tolerance | 1.777 % | System
| | | Information | Vout Tolerance based on IC Tolerance (no load) and voltage divider resistors if applicable
30. Vout p-p | 5.999 mV | System
| | | Information | Peak-to-peak output ripple voltage

## Design Inputs

Name | Value | Description
| Iout | | 500.0 m | Maximum Output Current
VinMax | 28.0 | Maximum input voltage
VinMin | 5.3 | Minimum input voltage
Vout | 5.0 | Output Voltage
| base_pn | | TPS54202H | Base Product Number
source | DC | Input Source Type
Ta | 30.0 | Ambient temperature


Copyright © 2026, Texas Instruments Incorporated | 6 | ti.com/webench

## Assembly

## Component Testing

Some published data on components in datasheets such as Capacitor ESR and Inductor DC resistance is based on conservative values that will guarantee that the components always exceed the specification. For design purposes it is usually better to work with typical values. Since this data is not always available it is a good practice to measure the Capacitance and ESR values of Cin and Cout, and the inductance and DC resistance of L1 before assembly of the board. Any large discrepancies in values should be electrically simulated in WEBENCH to check for instabilities and thermally simulated in WebTHERM to make sure critical temperatures are not exceeded.
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

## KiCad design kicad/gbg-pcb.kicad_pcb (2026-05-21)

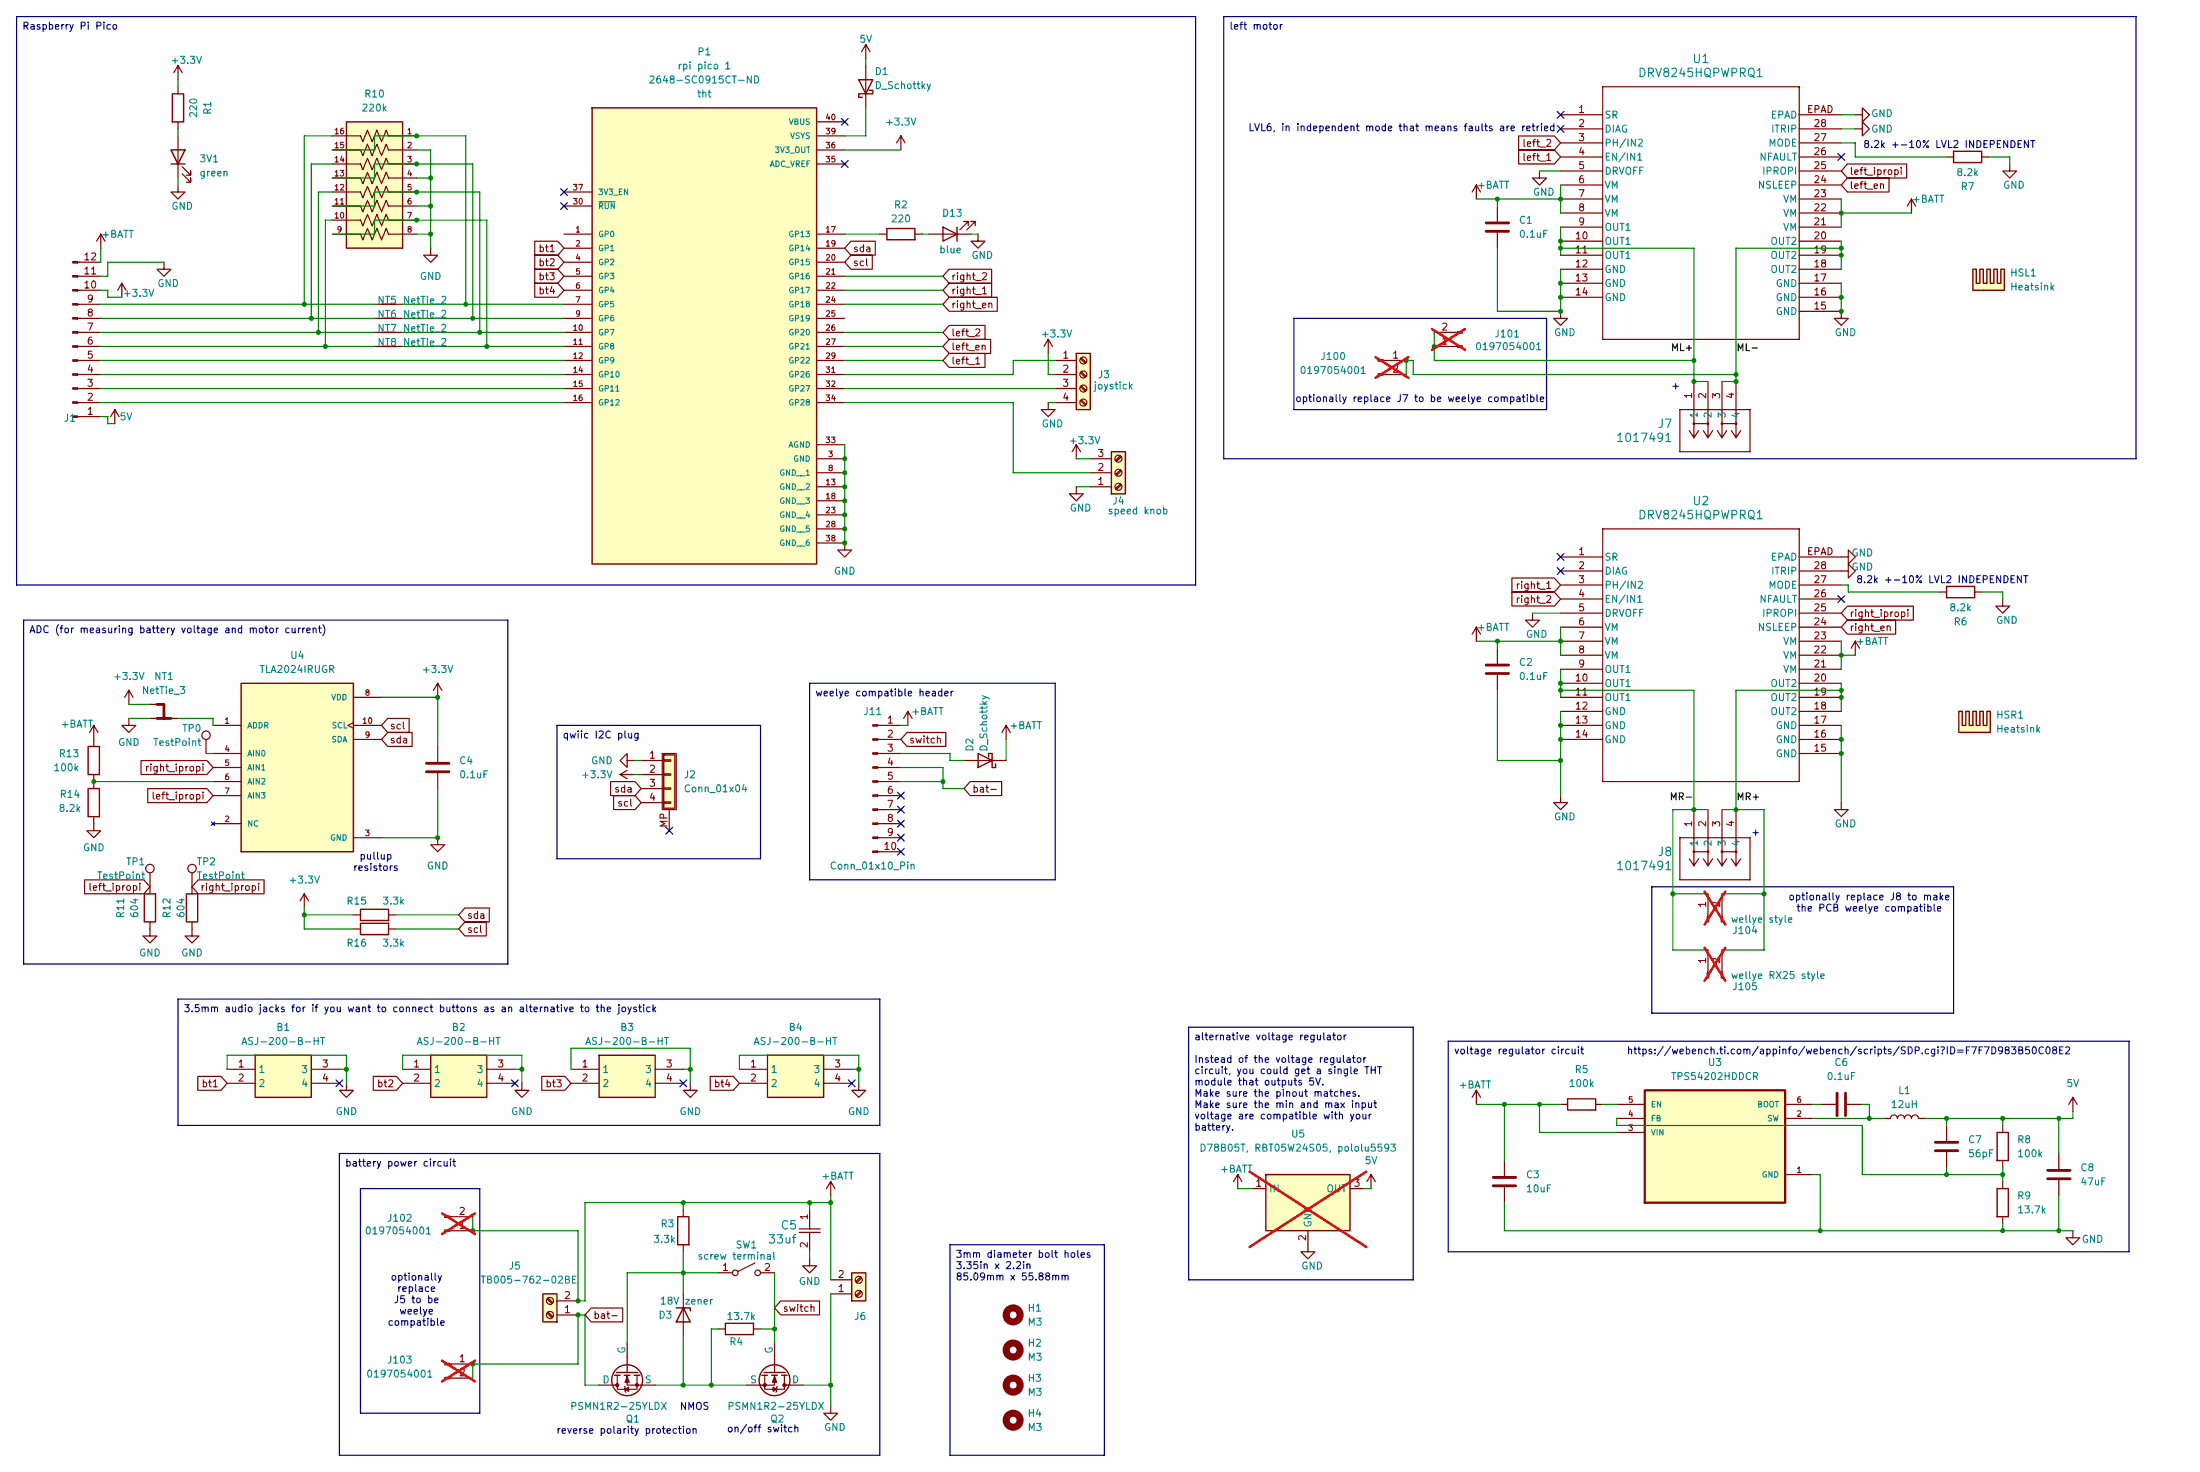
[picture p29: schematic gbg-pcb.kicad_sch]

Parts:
3V1: green; LED_D3.0mm; Manufacturer_Part_Number BL-B2141K; digikey_part_number 2007-BL-B2141K-ND
B1, B2, B3, B4: ASJ-200-B-HT; ASJ200BHT; Manufacturer_Part_Number ASJ-200-B-HT; Mouser Part Number 737-ASJ-200-B-HT
C1, C2, C4, C6: 0.1uF; C_0603_1608Metric; Manufacturer_Part_Number CGA3E2X7R1H104K080AA; digikey_part_number 445-5666-1-ND
C3: 10uF; C_1210_3225Metric; Manufacturer_Part_Number MSASU32MSB5106KPNA01; digikey_part_number 587-MSASU32MSB5106KPNA01CT-ND
C5: 33uf; CAP_KK-8x8_KEM; Manufacturer_Part_Number A759KK336M1JAAE036; digikey_part_number 399-A759KK336M1JAAE036-ND
C7: 56pF; C_0603_1608Metric; Manufacturer_Part_Number CC0603JRNPO9BN560; digikey_part_number 311-1066-1-ND
C8: 47uF; C_1210_3225Metric; Manufacturer_Part_Number GRM32ER71A476KE15L; digikey_part_number 490-5312-1-ND
D1, D2: D_Schottky; D_SOD-123F; Manufacturer_Part_Number FS26; digikey_part_number 4786-FS26CT-ND
D3: 18V zener; D_SOD-123F; Manufacturer_Part_Number MMSZ5248B-E3-18; digikey_part_number MMSZ5248B-E3-18GICT-ND
D13: blue; LED_D5.0mm; Manufacturer_Part_Number BL-BBX1V4V-2-B02; digikey_part_number 2007-BL-BBX1V4V-2-B02-ND
H1, H2, H3, H4: M3; MountingHole_3.2mm_M3_ISO7380; Manufacturer_Part_Number DNP; digikey_part_number DNP
HSL1: Heatsink; heatsink 375424B00034G; Manufacturer_Part_Number 375424B00034G; digikey_part_number 375424B00034G-ND
HSR1: Heatsink; heatsink 375424B00034G; Manufacturer_Part_Number 375424B00034G; digikey_part_number 375424B00034G-ND
J1: 12 2.54mm pitch header pins; PinHeader_1x12_P2.54mm_Vertical; Manufacturer_Part_Number PH1-12-UA; digikey_part_number 2057-PH1-12-UA-ND
J2: Conn_01x04; JST_SH_BM04B-SRSS-TB_1x04-1MP_P1.00mm_Vertical; Manufacturer_Part_Number BM04B-SRSS-TB; digikey_part_number 455-BM04B-SRSS-TBCT-ND
J3: joystick; TC0403620000G; Manufacturer_Part_Number TC0403620000G; digikey_part_number TC0403620000G-ND
J4: speed knob; SAMESKY_TB0011-350-03GR; Manufacturer_Part_Number TB0011-350-03GR; digikey_part_number 2223-TB0011-350-03GR-ND
J5: TB005-762-02BE; CUI_TB005-762-02BE; Manufacturer_Part_Number TB005-762-02BE; digikey_part_number 102-6189-ND
J6: screw terminal; EBBA-02-C-SS-BU; Manufacturer_Part_Number EBBA-02-C-SS-BU; digikey_part_number 2057-EBBA-02-C-SS-BU-ND
J7, J8: 1017491; CONN_1017491; Manufacturer_Part_Number 1017491; digikey_part_number 277-17493-ND
J11: Conn_01x10_Pin; PinHeader_1x10_P2.54mm_Vertical; Manufacturer_Part_Number PH1-10-UA; digikey_part_number 2057-PH1-10-UA-ND
J100, J101, J102, J103: 0197054001; Manufacturer_Part_Number 0197054001; digikey_part_number WM2982-ND; not fitted
J104: wellye style; CONN02_2159151002_MOL; Manufacturer_Part_Number 2159151002; digikey_part_number 23-2159151002-ND; not fitted
J105: wellye RX25 style; TE_1-1123723-2; Manufacturer_Part_Number 1-1123723-2; digikey_part_number A111830-ND; not fitted
L1: 12uH; IND_SRR6038-120Y; Manufacturer_Part_Number SRR6038-120Y; digikey_part_number SRR6038-120YCT-ND
NT1: NetTie_3; SolderJumper-3_P1.3mm_Bridged12_RoundedPad1.0x1.5mm; Manufacturer_Part_Number DNP; digikey_part_number DNP
NT5, NT6, NT7, NT8: NetTie_2; SolderJumper-2_P1.3mm_Bridged_RoundedPad1.0x1.5mm; Manufacturer_Part_Number DNP; digikey_part_number DNP
P1: rpi pico 1; RaspberryPi_Pico_Common_SMD; Manufacturer_Part_Number SC0915; digikey_part_number 2648-SC0915CT-ND
Q1, Q2: PSMN1R2-25YLDX; LFPAK56; Manufacturer_Part_Number PSMN1R2-25YLDX; digikey_part_number 1727-2496-1-ND
R1, R2: 220; R_0805_2012Metric; Manufacturer_Part_Number CRCW0805220RJNEA; digikey_part_number 541-220ACT-ND
R3, R15, R16: 3.3k; R_0805_2012Metric; Manufacturer_Part_Number CRCW08053K30FKEA; digikey_part_number 541-3.30KCCT-ND
R4, R9: 13.7k; R_0805_2012Metric; Manufacturer_Part_Number CRCW080513K7FKEA; digikey_part_number 541-13.7KCCT-ND
R5, R8, R13: 100k; R_0805_2012Metric; Manufacturer_Part_Number CRCW0805100KFKEA; digikey_part_number 541-100KCCT-ND
R6, R7, R14: 8.2k; R_0805_2012Metric; Manufacturer_Part_Number CRCW08058K20JNEA; digikey_part_number 541-8.2KACT-ND
R10: 220k; YC248-JR; Mfr PN YC248-JR-07220KL; digikey_part_number 13-YC248-JR-07220KLCT-ND
R11, R12: 604; R_0805_2012Metric; Manufacturer_Part_Number CRCW0805604RFKEA; digikey_part_number 541-604CCT-ND
SW1: screw terminal; EBBA-02-C-SS-BU; Manufacturer_Part_Number EBBA-02-C-SS-BU; digikey_part_number 2057-EBBA-02-C-SS-BU-ND
TP0: TestPoint; TestPoint_THTPad_D2.0mm_Drill1.0mm; Manufacturer_Part_Number DNP; digikey_part_number DNP
TP1, TP2: TestPoint; TestPoint_Pad_D2.0mm; Manufacturer_Part_Number DNP; digikey_part_number DNP
U1, U2: DRV8245HQPWPRQ1; HTSSOP28_PWP_TEX; Manufacturer_Part_Number DRV8245HQPWPRQ1; digikey_part_number 296-DRV8245HQPWPRQ1CT-ND
U3: TPS54202HDDCR; SOT95P280X110-6N tps54202HDDCR; Manufacturer_Part_Number TPS54202HDDCR; digikey_part_number 296-44396-1-ND
U4: TLA2024IRUGR; IC_TLA2024IRUGR; Mfr PN TLA2024IRUGR; digikey_part_number 296-51661-1-ND
U5: D78B05T, RBT05W24S05, pololu5593; D78B05T-1.0; not fitted

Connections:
5V: C7.1, C8.1, D1.2 (A), J1.1, L1.2, R8.1, U5.3 (OUT)
+3.3V: C4.1, J1.10, J2.2, J3.2, J4.3, NT1.3, P1.36 (3V3_OUT), R1.1, R15.1, R16.1, U4.8 (VDD)
+BATT: C1.1, C2.1, C3.1, C5.1, D2.1 (K), J1.12, J5.2, J6.2, J11.1, J102.1, J102.2, R3.1, R5.1, R13.1, U1.6 (VM), U1.7 (VM), U1.8 (VM), U1.21 (VM), U1.22 (VM), U1.23 (VM), U2.6 (VM), U2.7 (VM), U2.8 (VM), U2.21 (VM), U2.22 (VM), U2.23 (VM), U3.3 (VIN), U5.1 (IN)
/ML+: J7.1, J7.2, J101.1, J101.2, U1.9 (OUT1), U1.10 (OUT1), U1.11 (OUT1)
/ML-: J7.3, J7.4, J100.1, J100.2, U1.18 (OUT2), U1.19 (OUT2), U1.20 (OUT2)
/MR+: J8.3, J8.4, J104.2, J105.2, U2.18 (OUT2), U2.19 (OUT2), U2.20 (OUT2)
/MR-: J8.1, J8.2, J104.1, J105.1, U2.9 (OUT1), U2.10 (OUT1), U2.11 (OUT1)
GND: 3V1.1 (K), B1.1, B1.3, B2.1, B2.3, B3.1, B3.3, B4.1, B4.3, C1.2, C2.2, C3.2, C4.2, C5.2, C8.2, D13.1 (K), J1.11, J2.1, J3.4, J4.1, J6.1, NT1.1, P1.3 (GND), P1.8 (GND__1), P1.13 (GND__2), P1.18 (GND__3), P1.23 (GND__4), P1.28 (GND__5), P1.33 (AGND), P1.38 (GND__6), Q2.5 (D), R6.1, R7.1, R9.2, R10.2, R10.4, R10.6, R10.8, R11.1, R12.1, R14.2, U1.5 (DRVOFF), U1.12 (GND), U1.13 (GND), U1.14 (GND), U1.15 (GND), U1.16 (GND), U1.17 (GND), U1.28 (ITRIP), U1.EPAD, U2.5 (DRVOFF), U2.12 (GND), U2.13 (GND), U2.14 (GND), U2.15 (GND), U2.16 (GND), U2.17 (GND), U2.28 (ITRIP), U2.EPAD, U3.1 (GND), U4.3 (GND), U5.2 (GND); also elsewhere on the board
unnamed: 3V1.2 (A), R1.2
unnamed: D1.1 (K), P1.39 (VSYS)
unnamed: D2.2 (A), J11.3
unnamed: D3.2 (A), Q1.1 (S), Q1.2, Q1.3, Q2.1 (S), Q2.2, Q2.3, R4.1
unnamed: D3.1 (K), Q1.4 (G), R3.2, SW1.1 (A)
unnamed: D13.2 (A), R2.2
unnamed: J1.2, P1.16 (GP12)
unnamed: J1.3, P1.15 (GP11)
unnamed: J1.4, P1.14 (GP10)
unnamed: J1.5, P1.12 (GP9)
unnamed: J1.6, NT8.1, R10.10
unnamed: J1.7, NT7.1, R10.12
unnamed: J1.8, NT6.1, R10.14
unnamed: J1.9, NT5.1, R10.16
unnamed: J3.1, P1.31 (GP26)
unnamed: J3.3, P1.32 (GP27)
unnamed: J4.2, P1.34 (GP28)
unnamed: NT5.2, P1.7 (GP5), R10.1, R10.15
unnamed: NT6.2, P1.9 (GP6), R10.3, R10.13
unnamed: NT7.2, P1.10 (GP7), R10.5, R10.11
unnamed: NT8.2, P1.11 (GP8), R10.7, R10.9
unnamed: P1.17 (GP13), R2.1
unnamed: R7.2, U1.27 (MODE)
unnamed: R6.2, U2.27 (MODE)
unnamed: C6.2, U3.6 (BOOT)
unnamed: R5.2, U3.5 (EN)
unnamed: C7.2, R8.2, R9.1, U3.4 (FB)
unnamed: C6.1, L1.1, U3.2 (SW)
unnamed: NT1.2, U4.1 (ADDR)
unnamed: TP0.1 (1_1), U4.4 (AIN0)
unnamed: R13.2, R14.1, U4.6 (AIN2)
bat-: J5.1, J11.4, J11.5, J103.1, J103.2, Q1.5 (D)
bt1: B1.2, P1.2 (GP1)
bt2: B2.2, P1.4 (GP2)
bt3: B3.2, P1.5 (GP3)
bt4: B4.2, P1.6 (GP4)
left_1: P1.29 (GP22), U1.4 (EN/IN1)
left_2: P1.26 (GP20), U1.3 (PH/IN2)
left_en: P1.27 (GP21), U1.24 (NSLEEP)
left_ipropi: R11.2, TP1.1 (1_1), U1.25 (IPROPI), U4.7 (AIN3)
right_1: P1.22 (GP17), U2.3 (PH/IN2)
right_2: P1.21 (GP16), U2.4 (EN/IN1)
right_en: P1.24 (GP18), U2.24 (NSLEEP)
right_ipropi: R12.2, TP2.1 (1_1), U2.25 (IPROPI), U4.5 (AIN1)
scl: J2.4, P1.20 (GP15), R16.2, U4.10 (SCL)
sda: J2.3, P1.19 (GP14), R15.2, U4.9 (SDA)
switch: J11.2, Q2.4 (G), R4.2, SW1.2 (B)

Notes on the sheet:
reverse polarity protection
8.2k +-10% LVL2 INDEPENDENT
LVL6, in independent mode that means faults are retried
optionally replace J8 to make the PCB weelye compatible
optionally replace J7 to be weelye compatible
NMOS
on/off switch
pullup resistors
optionally replace J5 to be weelye compatible
3mm diameter bolt holes 3.35in x 2.2in 85.09mm x 55.88mm
ADC (for measuring battery voltage and motor current)
weelye compatible header
battery power circuit
3.5mm audio jacks for if you want to connect buttons as an alternative to the joystick
alternative voltage regulator Instead of the voltage regulator circuit, you could get a single THT module that outputs 5V. Make sure the pinout matches. Make sure the min and max input voltage are compatible with your battery.
voltage regulator circuit https://webench.ti.com/appinfo/webench/scripts/SDP.cgi?ID=F7F7D983B50C08E2
qwiic I2C plug
left motor
Raspberry Pi Pico

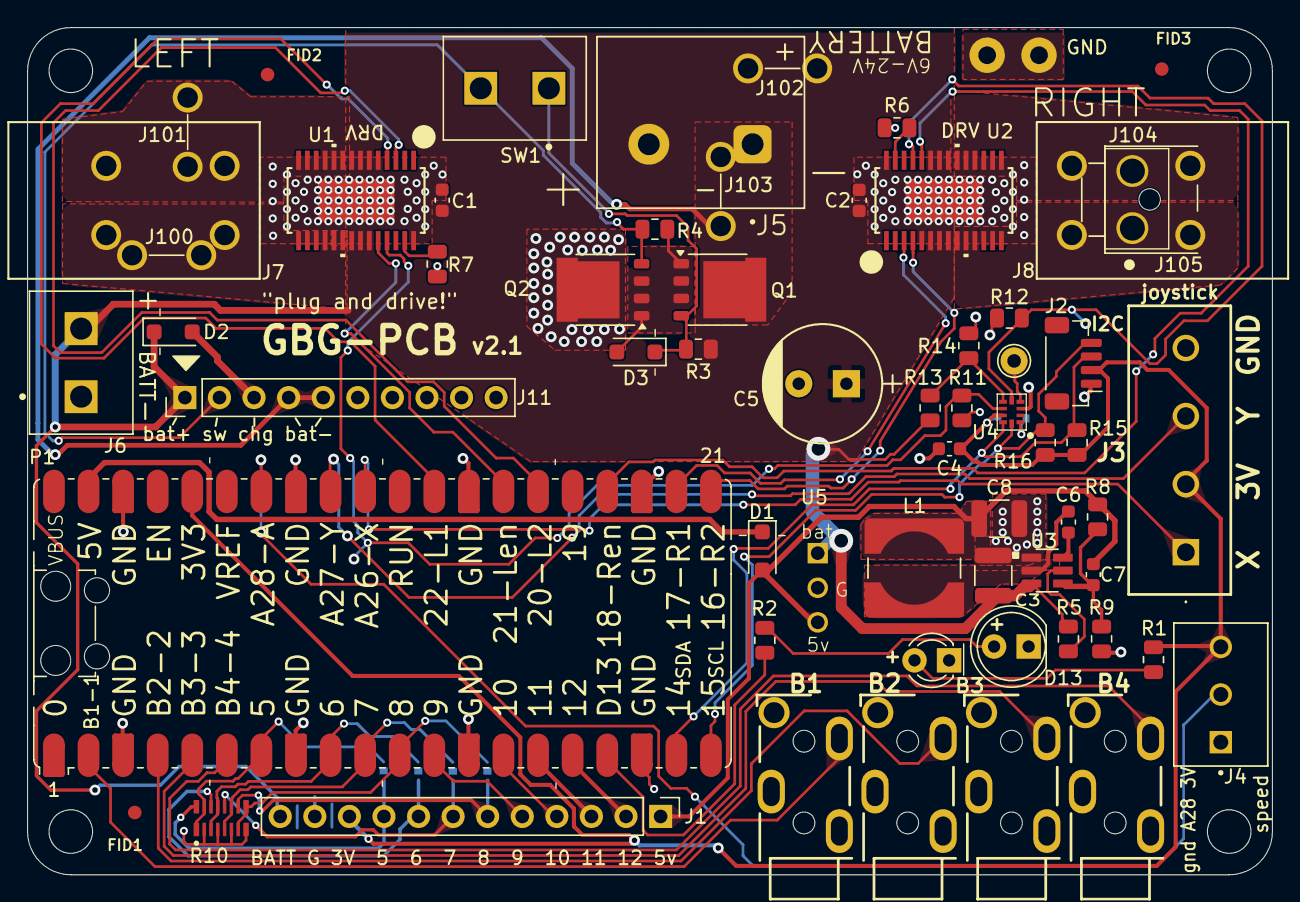
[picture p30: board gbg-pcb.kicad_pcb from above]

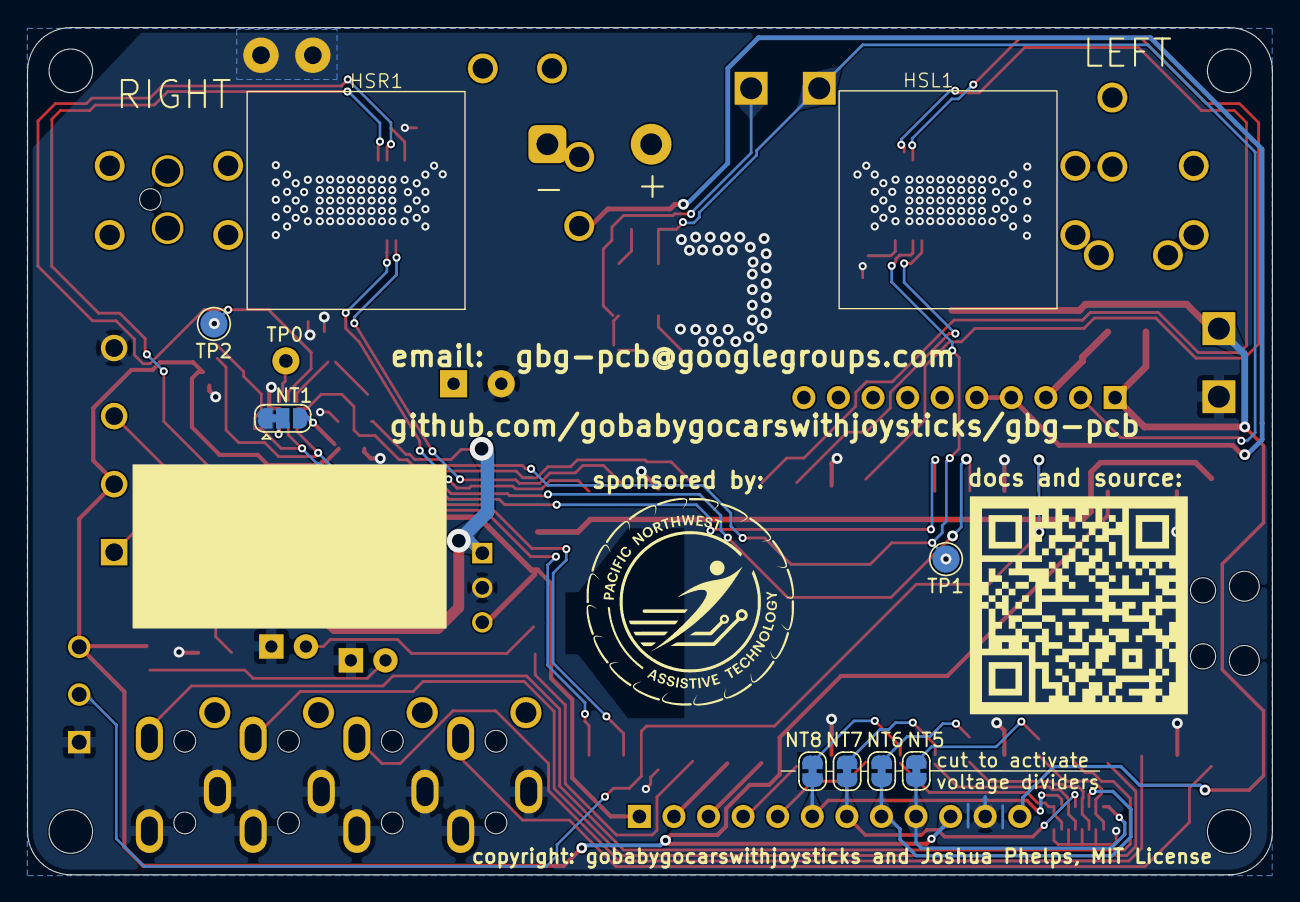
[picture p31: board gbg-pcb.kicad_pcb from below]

Board: 2 copper layers, 91.4 x 62.2 mm, 76 parts (9 on the bottom side), 55 nets.

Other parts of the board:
FID1: 1; Fiducial_1mm_Mask3mm
FID2: 2; Fiducial_1mm_Mask3mm
FID3: 3; Fiducial_1mm_Mask3mm
JGND2: Conn_01x02; TestPoint_Bridge_Pitch3.81mm_Drill1.3mm

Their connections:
GND: JGND2.1 (Pin_1_1); also elsewhere on the board

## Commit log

2025-03-11 add diodes
    [POWERDI5_DIO.step, gbg-pcb.kicad_pcb, gbg-pcb.kicad_sch]
2025-03-12 begin re-arranging pico
    [gbg-pcb.kicad_pcb, gbg-pcb.kicad_sch]
2025-03-12 add motor driver signal traces
    [gbg-pcb.kicad_pcb, gbg-pcb.kicad_sch]
2025-03-13 arrange parts
    [gbg-pcb.kicad_pcb, gbg-pcb.kicad_sch]
2025-03-14 work on BOM
    [1017514.stp, 1017526.stp, gbg-pcb.kicad_pcb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]
2025-03-14 change motor and power terminals
    [OSTTC0201X2.stp, VP0265840000G.STEP, gbg-pcb.kicad_pcb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]
2025-03-14 update kicad to v9.0.0
    [gbg-pcb.kicad_pcb, gbg-pcb.kicad_sch]
2025-03-14 kicad 9.0.0
    [gbg-pcb.kicad_pcb, gbg-pcb.kicad_sch]
2025-03-15 automatically render images
    [gbg-pcb.kicad_pcb, gbg-pcb.kicad_sch]
2025-03-15 clean up fil zones
    [gbg-pcb.kicad_pcb]
2025-03-16 change inductor
    [WBBOMDesign12(1).csv, WBBOMDesign12.csv, gbg-pcb.kicad_pcb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]
2025-03-16 export bom
    [BOM.csv, gbg-pcb.kicad_sch]
2025-03-16 BOT process website
    [BOM.csv]
2025-03-16 move silkscreen
    [gbg-pcb.kicad_pcb]
2025-03-16 label pico pins
    [gbg-pcb.kicad_pcb, gbg-pcb.kicad_sch]
2025-03-17 move traces
    [gbg-pcb.kicad_pcb, gbg-pcb.kicad_sch]
2025-03-17 adjust trace width and ground vias
    [gbg-pcb.kicad_pcb, gbg-pcb.kicad_sch]
2025-03-17 BOT process kicad
2025-03-17 update BOM generator
2025-03-17 add readme
    [gbg-pcb.kicad_pcb]
2025-03-18 change mosfets
    [BOM.csv, gbg-pcb.kicad_pcb, gbg-pcb.kicad_sch]
2025-03-18 adjust traces
    [gbg-pcb.kicad_pcb, gbg-pcb.kicad_sch]
2025-03-23 reset main
    [0398800304.stp, 1017503.stp, 1017514.stp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]
2025-03-23 copy from ifx-2
    [0398800304.stp, 1017503.stp, 1017514.stp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]
2025-03-24 change and label capacitors
    [gbg-pcb.kicad_pcb, gbg-pcb.kicad_sch]
2025-03-24 round corners
    [gbg-pcb.kicad_pcb]
2025-03-26 export solder paste stencil DXF
    [gbg-pcb-F_Mask.dxf]
2025-03-27 update values for bom
    [gbg-pcb.kicad_pcb, gbg-pcb.kicad_sch]
2025-04-04 fix mosfet circuit
    [gbg-pcb.kicad_pcb, gbg-pcb.kicad_sch]
2025-04-05 adjust labels
    [gbg-pcb.kicad_pcb, gbg-pcb.kicad_sch]
2025-04-06 adjust layout and heatsink
    [gbg-pcb.kicad_pcb, gbg-pcb.kicad_sch, sk582.stp]
2025-04-06 adjust layout
    [gbg-pcb.kicad_pcb, gbg-pcb.kicad_sch]
2025-04-10 Update and rename GBG-PCB.md to index
2025-04-13 add circuit diagram
2025-04-23 v1.2 (update BOM and adjust silkscreen)
    [gbg-pcb.kicad_pcb, gbg-pcb.kicad_sch]
2025-04-25 different heatsinks
    [gbg-pcb.kicad_pcb, gbg-pcb.kicad_sch, v2027b.stp]
2025-04-26 adjust heatsink
    [gbg-pcb.kicad_pcb, gbg-pcb.kicad_sch]
2025-05-01 update docs for how to get boards
2025-06-02 change pcb to use 26mm thermal tape and start instructions
    [gbg-pcb.kicad_pcb, gbg-pcb.kicad_sch]
2025-06-04 add 3d models to library
    [CP_Radial_D10.0mm_P5.00mm.step, C_1206_3216Metric.step, D_SOD-123F.step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]
2025-06-04 update model for header pins
    [PinHeader_1x12_P2.54mm_Vertical.step, gbg-pcb.kicad_pcb]
2025-06-18 update how to get boards
2025-08-25 update images of gbg-pcb
2025-09-16 update readme for pcb production
2025-12-22 starting pcb layout
    [1017491.stp, A759KC276M1JAAE054.step, A759KK336M1JAAE036.step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]
2025-12-22 some layout
    [gbg-pcb.kicad_pcb]
2025-12-22 working on layout
    [EBBA-02-C-SS-BU--3DModel-STEP-510211.STEP, TC0403620000G.stp, gbg-pcb.kicad_pcb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]
2025-12-23 work on layout
    [gbg-pcb.kicad_pcb, gbg-pcb.kicad_sch]
2025-12-23 draw traces
    [gbg-pcb.kicad_pcb, gbg-pcb.kicad_sch]
2026-04-14 BOT render images
    [gbg-pcb.step]
2026-04-16 fix script
    [gbg-pcb.kicad_pcb, gbg-pcb.kicad_sch]
2026-04-18 fix parts for voltage regulator and add weelye tabs
    [WBBOMDesign12(1).csv, WBBOMDesign12.csv, gbg-pcb.kicad_pcb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]
2026-04-18 adjust script
    [gbg-pcb.step]
2026-04-18 update script
    [gbg-pcb.step]
2026-04-19 add sponsor logo and work on readme
    [gbg-pcb.kicad_pcb]
2026-04-19 add new email
    [gbg-pcb.kicad_pcb]
2026-04-19 arrange schematic
    [gbg-pcb.kicad_pcb, gbg-pcb.kicad_sch]
2026-04-28 BOT Update interactive BOM
2026-05-02 adjust silkscreen and minor layout changes
    [gbg-pcb.kicad_pcb]
2026-05-03 arrange silkscreen and traces
    [gbg-pcb.kicad_pcb]
2026-05-05 add vias
    [gbg-pcb.kicad_pcb, gbg-pcb.kicad_sch]
2026-05-05 work on right motor connection
    [gbg-pcb.kicad_pcb, gbg-pcb.kicad_sch]
2026-05-07 updates from assembling V2.1, and silkscreen
    [gbg-pcb.kicad_pcb, gbg-pcb.kicad_sch]
2026-05-11 change resistors
    [gbg-pcb.kicad_pcb, gbg-pcb.kicad_sch]
2026-05-12 adjust layout and heatsink pads
    [gbg-pcb.kicad_pcb, gbg-pcb.kicad_sch]
2026-05-21 change weelye plug pinout after testing
    [gbg-pcb.kicad_pcb, gbg-pcb.kicad_sch]

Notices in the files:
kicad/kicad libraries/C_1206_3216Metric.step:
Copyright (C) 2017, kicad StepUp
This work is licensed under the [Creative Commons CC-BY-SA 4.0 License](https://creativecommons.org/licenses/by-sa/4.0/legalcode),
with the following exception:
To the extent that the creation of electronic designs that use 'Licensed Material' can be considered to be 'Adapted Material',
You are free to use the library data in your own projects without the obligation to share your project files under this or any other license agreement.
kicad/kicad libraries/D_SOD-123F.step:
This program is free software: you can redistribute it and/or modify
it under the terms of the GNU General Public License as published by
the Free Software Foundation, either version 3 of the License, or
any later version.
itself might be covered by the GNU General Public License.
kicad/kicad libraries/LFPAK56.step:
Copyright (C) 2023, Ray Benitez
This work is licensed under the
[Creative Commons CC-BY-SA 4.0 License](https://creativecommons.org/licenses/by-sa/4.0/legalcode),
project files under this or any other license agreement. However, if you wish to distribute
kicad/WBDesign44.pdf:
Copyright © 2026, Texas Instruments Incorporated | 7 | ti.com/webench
